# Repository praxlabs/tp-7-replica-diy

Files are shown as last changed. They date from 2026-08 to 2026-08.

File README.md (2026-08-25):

# DIY TP-7: Motorized-Reel Field Recorder (Open Source Hardware & Firmware)

An open-source digital replica and hardware implementation of the **Teenage Engineering TP-7 Field Recorder**. Features a physical motorized tape reel spool, contactless magnetic angle scrubbing, digital MEMS microphone recording, 24-bit I2S audio processing, dual-stage rocker shuttle, and Bluetooth LE transcription streaming on an **ESP32-WROOM-32E** dual-core microcontroller.

---

## 🌟 Quick Links & Documentation Index

| Resource | Description | Format |
| :--- | :--- | :--- |
| 🕹️ [**Digital Twin Simulator**](index.html) | Interactive web-based hardware simulator with Web Audio engine and touch scrubbing | `HTML5 / JS` |
| 📘 [**Documentation CLI Hub**](documentation.cmd) | Interactive Windows command center for all guides, sketches, and tools | `documentation.cmd` |
| 🔌 [**Breadboard Prototyping Guide**](Breadboard-Prototyping-Guide.md) | Step-by-step wiring diagrams, dual-rail layout, and noise isolation rules | `Markdown` |
| 🧪 [**Breadboard Hardware Diagnostic Tool**](TP7_Replica/Breadboard_Subsystem_Tester.ino) | Interactive serial monitor diagnostic tool for testing sensors and motors | `Arduino (.ino)` |
| 💻 [**Main Firmware (v2.0)**](TP7_Replica/TP7_Replica.ino) | FreeRTOS dual-core firmware with touch-to-pause and memo recording | `Arduino (.ino)` |
| 🛠️ [**Arduino & ESP32 Setup Guide**](Arduino-Prototyping-Setup-Guide.md) | Complete guide for configuring Arduino IDE 2.x and flashing the ESP32 | `Markdown` |
| 📐 [**Custom PCB & Manufacturing Guide**](PCB-Design-And-Manufacturing-Guide.md) | 4-layer PCB stackup, KiCad netlist, and Gerber ordering instructions | `Markdown` |
| 📋 [**Required Parts List & Sourcing BOM**](Required-Parts-List-And-Sourcing.md) | Full bill of materials with footprints, part numbers, and suppliers | `Markdown` |
| ⚖️ [**Commercialization & Legal Guide**](DIY-TP7-Commercialization-And-Legal-Guide.pdf) | IP analysis (trade dress, patents, trademarks), FCC/CE, and battery laws | `PDF Document` |
| 🧊 [**3D Printable STL Files**](3D_Models/) | Production-ready STL models for unibody chassis, motorized reel, and rocker | `3D STL Files` |

---

## 📐 System Architecture

```
                          ┌─────────────────────────────┐
                          │         ESP32-WROOM         │
                          │   (Dual-Core 240MHz, BLE)   │
                          └───────────────┬─────────────┘
         ┌───────────┬───────────┬────────┼────────┬───────────┬───────────┐
         │           │           │        │        │           │           │
    I2S Mic      I2S Amp     I2C Bus   SPI Bus   PWM/GPIO    UART/USB   ADC (Batt)
   (INMP441)   (MAX98357A)  (AS5600  (microSD)  (DRV8833     (USB-C     (Voltage
                             Encoder,            Motor,       Audio /    Divider)
                             SSD1306             Buttons)     Data)
                             OLED)
```

### FreeRTOS Dual-Core Task Allocation
* **Core 1 (High Real-Time Priority - Pri 3):** Dedicated 44.1kHz / 16-bit I2S DMA double-buffered audio streaming for INMP441 microphone recording and MAX98357A Class-D speaker playback.
* **Core 0 (UI & Motor Loop - 500 Hz):** Polls the AS5600 magnetic rotary sensor via fast I2C, computes angular velocity, detects user touch-to-pause motor stall, and drives DRV8833 H-bridge PWM.

---

## 🎛️ Key Hardware Features (Teenage Engineering TP-7 Specifications)

1. **Motorized Tape Reel (Signature Mechanism):**
   * Driven by an N20 micro metal gearmotor (100:1 reduction) via DRV8833 PWM.
   * Position tracked by an **AS5600 12-bit contactless magnetic encoder** (4096 counts per rotation) paired with a 6x3mm N35 diametric magnet.
   * **Touch-to-Pause:** Placing a finger on the spinning reel detects motor stall through angular velocity differentiation, smoothly halting playback without stopping the tape head.
2. **Dedicated Controls:**
   * **MEMO Button:** Instant hold-to-record voice memo shortcut.
   * **REC Button:** Project recording toggle with red LED status glow.
   * **PLAY / PAUSE:** Standard playback toggle.
   * **2-Stage Rocker Switch:** Fast-forward and rewind shuttle scrub with speed acceleration.
3. **Multi-Jack Audio I/O:**
   * 3x 3.5mm TRRS two-way jacks for stereo line-in, microphone input, cue monitoring, and headphones.
4. **Wireless Companion Sync:**
   * Streams audio chunks over Bluetooth Low Energy (BLE) for real-time speech transcription.

---

## 🚀 How to Run the Project

### 1. Launch the Digital Twin Simulator
Open [`index.html`](index.html) in Google Chrome, Firefox, or Edge. You can interact with the virtual motorized reel, record via your computer microphone, and test audio scrubbing directly in your browser.

### 2. Open the Documentation Hub
Double-click [`documentation.cmd`](documentation.cmd) on Windows to launch an interactive menu for accessing all guides, schematics, 3D STL files, and firmware sketches.

### 3. Flash to Hardware
1. Connect your ESP32 board via USB.
2. Open [`TP7_Replica/TP7_Replica.ino`](TP7_Replica/TP7_Replica.ino) in **Arduino IDE**.
3. Select **Board: ESP32 Dev Module** and click **Upload**.

---

## 📜 License & Compliance Note
This project is open-source hardware and software created for educational, prototyping, and research purposes. *"TP-7"*, *"Teenage Engineering"*, and *"Field System"* are registered trademarks of Teenage Engineering AB. Please review [`DIY-TP7-Commercialization-And-Legal-Guide.pdf`](DIY-TP7-Commercialization-And-Legal-Guide.pdf) before considering any commercial distribution.

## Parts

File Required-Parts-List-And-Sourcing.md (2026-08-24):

# DIY TP-7 Field Recorder: Required Parts List & Sourcing Guide

A complete, production-ready Bill of Materials (BOM) for building the DIY Teenage Engineering TP-7 Replica. Every component has been selected for optimal audio fidelity, low mechanical jitter, power efficiency, and compact fit inside the 3D-printed or CNC enclosure.

---

## 1. Primary Electronics & ICs

| Ref Des | Part Name | Manufacturer / MPN | Package / Footprint | Description | Est. Cost (USD) | Sourcing Options |
| :--- | :--- | :--- | :--- | :--- | :--- | :--- |
| **U1** | **ESP32-WROOM-32E** | Espressif Systems (`ESP32-WROOM-32E-N4` or DevKitC) | SMD Module (or 38-pin DIP DevBoard) | Dual-Core 240MHz MCU, 4MB Flash, BT/BLE 4.2, I2S Hardware Controller | $3.50 – $6.00 | [DigiKey](https://www.digikey.com) / [LCSC](https://www.lcsc.com) / [Mouser](https://www.mouser.com) |
| **U2** | **INMP441 MEMS Mic** | TDK InvenSense (`INMP441ACEZ-R7`) | Bottom-Port LGA-14 / Breakout | Omnidirectional Digital Microphone with integrated 24-bit I2S ADC (61 dB SNR) | $2.20 – $3.50 | [AliExpress](https://aliexpress.com) / [LCSC](https://www.lcsc.com) / [Amazon](https://amazon.com) |
| **U3** | **MAX98357A Amp** | Analog Devices / Maxim (`MAX98357AETE+T`) | 16-TQFN / Breakout | 3.2W Mono Class-D Audio Amplifier with built-in I2S DAC | $2.50 – $4.00 | [DigiKey](https://www.digikey.com) / [Adafruit](https://www.adafruit.com) / [LCSC](https://www.lcsc.com) |
| **U4** | **AS5600 Angle Sensor** | ams OSRAM (`AS5600-ASOT`) | SOIC-8 / Breakout Module | 12-Bit Programmable Contactless Magnetic Rotary Position Sensor (I2C 0x36) | $1.80 – $3.00 | [LCSC](https://www.lcsc.com) / [AliExpress](https://aliexpress.com) |
| **U5** | **DRV8833 Motor Driver** | Texas Instruments (`DRV8833PWPR`) | 16-HTSSOP / Breakout | Dual H-Bridge Motor Driver (1.5A RMS per channel, PWM speed control) | $1.50 – $2.50 | [DigiKey](https://www.digikey.com) / [LCSC](https://www.lcsc.com) / [Pololu](https://www.pololu.com) |
| **U6** | **WM8960 Audio Codec** | Cirrus Logic (`WM8960CGEFL/RV`) | 32-QFN / Waveshare Breakout | Low Power Stereo Codec with Class D Speaker Driver & 24-bit Stereo ADC/DAC | $7.00 – $11.00 | [LCSC](https://www.lcsc.com) / [Mouser](https://www.mouser.com) / [Waveshare](https://www.waveshare.com) |
| **U7** | **TP4056 + DW01A** | NanJing Top Power (`TP4056`) | SOP-8 / USB-C Charge Board | 1A Standalone Linear Li-Ion Battery Charger with Overcharge/Overdischarge Protection | $0.80 – $1.50 | [AliExpress](https://aliexpress.com) / [Amazon](https://amazon.com) |
| **DISP1** | **0.96" OLED Display** | Solomon Systech (`SSD1306` / `SSD1315`) | 128x64 I2C Monochrome OLED | Ultra-high contrast display for timecode, VU meters, file names, and battery level | $2.50 – $4.50 | [AliExpress](https://aliexpress.com) / [Amazon](https://amazon.com) |

---

## 2. Electromechanical, Motors & Mechanism

| Ref Des | Item Description | Specifications | Function / Notes | Est. Cost (USD) | Sourcing Options |
| :--- | :--- | :--- | :--- | :--- | :--- |
| **M1** | **N20 Micro Metal Gearmotor** | 6V 100RPM – 150RPM (100:1 reduction, 3mm D-Shaft) | Drives the tape reel spool smoothly without excessive gear chatter | $2.50 – $4.00 | [AliExpress](https://aliexpress.com) / [Pololu](https://www.pololu.com) / [Amazon](https://amazon.com) |
| **MAG1** | **Diametric Neodymium Magnet** | 6mm Diameter x 3mm Thickness, N35 / N52 | **Crucial:** Must be *diametrically magnetized* (poles on curved sides) for AS5600 | $0.80 – $1.50 | [SuperMagnetMan](https://supermagnetman.com) / [K&J Magnetics](https://kjmagnetics.com) / [AliExpress](https://aliexpress.com) |
| **SPK1** | **Miniature Dynamic Speaker** | 8 Ohm 1W – 2W, 20mm round x 4mm slim | Internal monitoring speaker | $1.20 – $2.00 | [DigiKey](https://www.digikey.com) / [LCSC](https://www.lcsc.com) |
| **J1, J2, J3** | **3.5mm TRRS Audio Jacks** | PJ-320A / CUI Devices `SJ-43514-SMT` | 4-Pole stereo + mic I/O jacks (Tip, Ring 1, Ring 2, Sleeve) | $0.60 ea ($1.80 total) | [LCSC](https://www.lcsc.com) / [DigiKey](https://www.digikey.com) |
| **J4** | **microSD Card Socket** | Push-Push SPI/SDIO SMD Socket | High-speed FAT32 / exFAT storage for 44.1kHz / 96kHz PCM WAV files | $0.70 – $1.20 | [LCSC](https://www.lcsc.com) / [DigiKey](https://www.digikey.com) |
| **J5** | **USB-C 16-Pin Receptacle** | TYPE-C 16P Female SMD (`TYPE-C-31-M-12`) | 5V 1A charging + USB Mass Storage / UAC 2.0 Audio Interface data | $0.40 – $0.90 | [LCSC](https://www.lcsc.com) |
| **SW1–SW4** | **Tactile SMD Pushbuttons** | 6x6x5mm or 4x4x1.5mm Soft-Click SMD | Record, Memo, Play/Stop, Mode switches | $0.15 ea ($0.60 total) | [LCSC](https://www.lcsc.com) / [DigiKey](https://www.digikey.com) |
| **SW5** | **2-Way Rocker Switch** | SPDT Center-Off Momentary Seesaw Rocker | Side Fast-Forward / Rewind shuttle control | $1.50 – $2.50 | [AliExpress](https://aliexpress.com) / [Mouser](https://www.mouser.com) |
| **BATT1** | **Rechargeable LiPo Cell** | 3.7V 1S 500mAh – 1000mAh (Model 602535 / 803040) | Provides 4 to 8 hours of continuous field recording | $4.50 – $7.00 | [Adafruit](https://www.adafruit.com) / [Amazon](https://amazon.com) |

---

## 3. Passive Components & Hardware Fasteners

| Quantity | Component Type | Value / Rating | Purpose |
| :--- | :--- | :--- | :--- |
| **8** | Ceramic Capacitor 0805 | 100nF (0.1µF) 50V X7R | High-frequency power rail decoupling |
| **4** | Tantalum / Electrolytic Cap | 10µF – 100µF 10V | Bulk decoupling for motor drive and audio amp |
| **4** | SMD Resistor 0805 | 4.7 kΩ 1% | I2C pull-up resistors for SDA / SCL lines |
| **2** | SMD Resistor 0805 | 5.1 kΩ 1% | USB Type-C CC1 / CC2 pull-down resistors (standard 5V negotiation) |
| **2** | SMD Resistor 0805 | 330 Ω 1% | LED current limiting resistors |
| **2** | SMD LED 0805 | Red (REC active), Amber (Charging) | Hardware status indicators |
| **4** | M2 Socket Cap Screws | M2 x 6mm Stainless Steel | Chassis assembly & bottom lid fastening |
| **4** | M2 Brass Heat-Set Threaded Inserts | M2 x 3.5mm OD 3.2mm | Heat-pressed into 3D-printed chassis standoffs |
| **1** | Miniature Ball Bearing (Optional) | 683ZZ (3mm ID x 7mm OD x 3mm Width) | Eliminates reel wobble and ensures whisper-quiet motorized spinning |

---

## 4. 3D Printable Enclosure Parts (Included in `/3D_Models`)

| File Name | Recommended Filament | Infill & Layer Height | Print Notes |
| :--- | :--- | :--- | :--- |
| `TP7_Main_Chassis_Top.stl` | Matte Black PETG or PLA Pro | 25% Gyroid, 0.16mm layer height | Print top-face up with tree supports for jack recesses |
| `TP7_Chassis_Bottom_Lid.stl` | Matte Black PETG / PLA Pro | 30% Infill, 0.20mm layer height | Flat on print bed, no supports needed |
| `TP7_Motorized_Tape_Reel.stl` | Silver / Anodized Grey PETG or Resin | 100% Solid, 0.12mm (Resin preferred) | Ensures smooth balanced rotation around N20 shaft |
| `TP7_Side_Rocker_Switch.stl` | Orange or Black PETG | 100% Solid, 0.12mm | High wear resistance for finger shuttle action |
| `TP7_Tactile_Button_Caps.stl` | Orange (REC) & Black (Play/Mode) | 100% Solid, 0.12mm | Print in sets of 4 |

---

## 5. Total Project Cost Summary

* **DIY Hand-Wired Prototype (Using Breakout Modules):** ~$45.00 – $65.00
* **Custom SMT Assembled PCB (JLCPCB 5-Board Run):** ~$75.00 – $95.00 total
* **Comparison with OEM Teenage Engineering TP-7:** **$1,499.00 retail** (Save over 94% while building your own customized field recorder!)

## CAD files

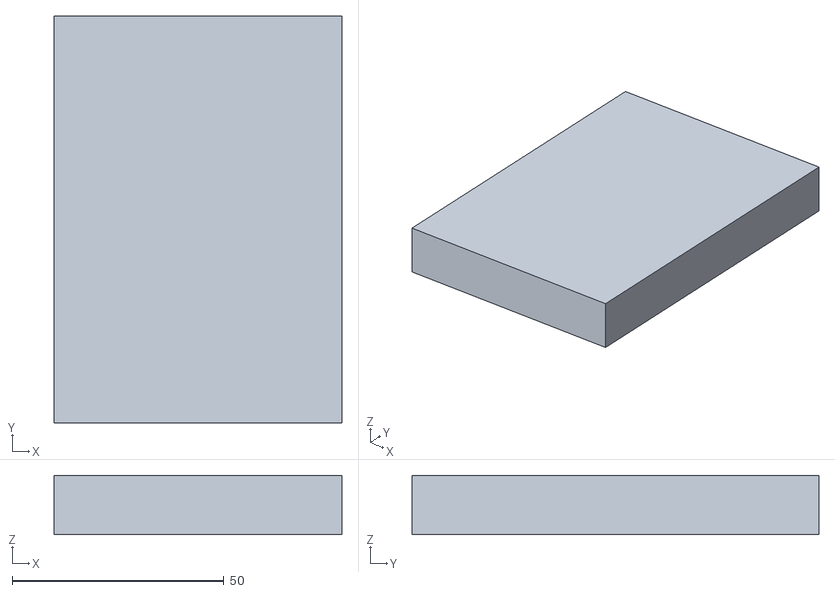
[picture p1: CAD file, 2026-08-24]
3D_Models/TP7_Main_Chassis_Top.stl
68.0 x 96.0 x 14.0

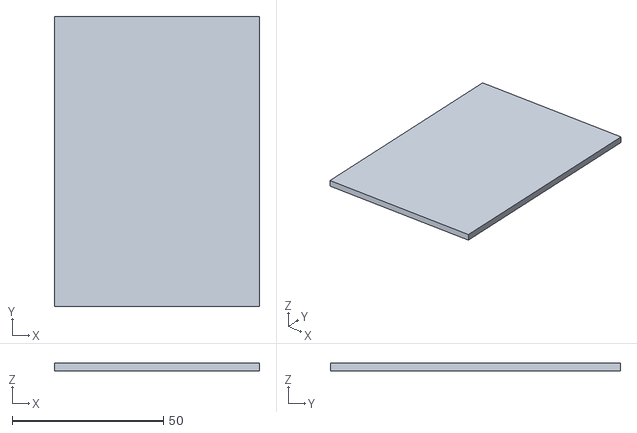
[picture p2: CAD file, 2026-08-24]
3D_Models/TP7_Chassis_Bottom_Lid.stl
68.0 x 96.0 x 2.50

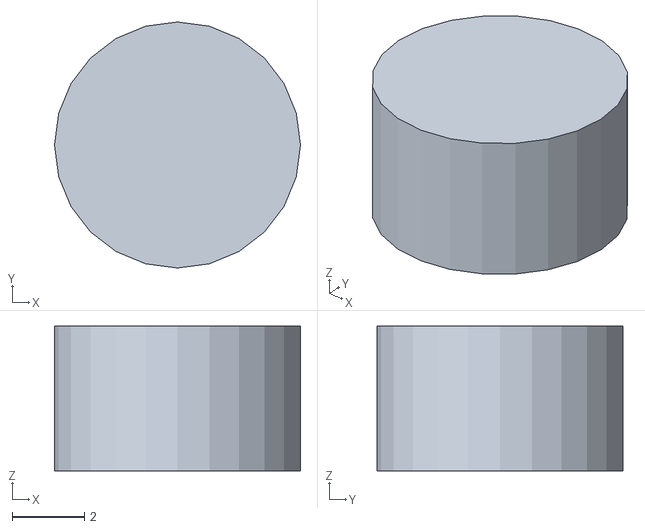
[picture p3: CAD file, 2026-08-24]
3D_Models/TP7_Tactile_Button_Caps.stl
6.80 x 6.80 x 4.00

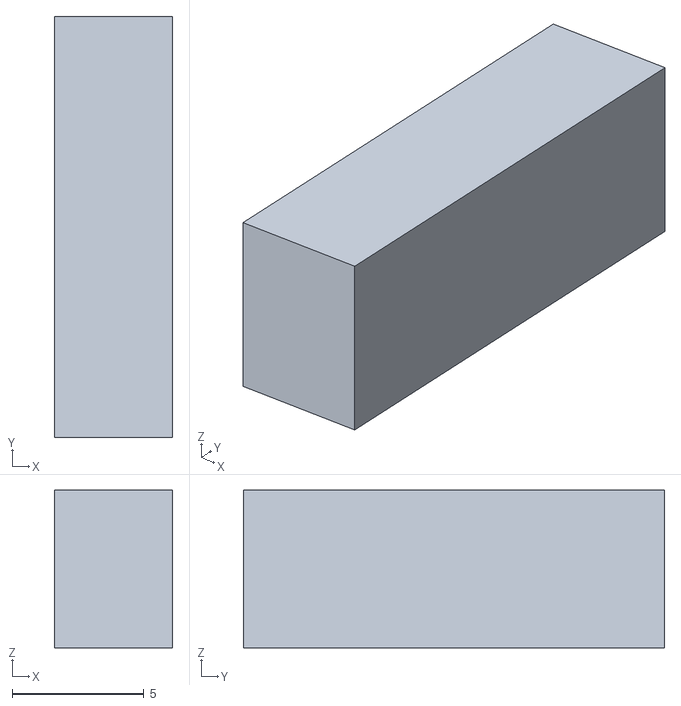
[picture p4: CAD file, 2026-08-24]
3D_Models/TP7_Side_Rocker_Switch.stl
4.50 x 16.0 x 6.00

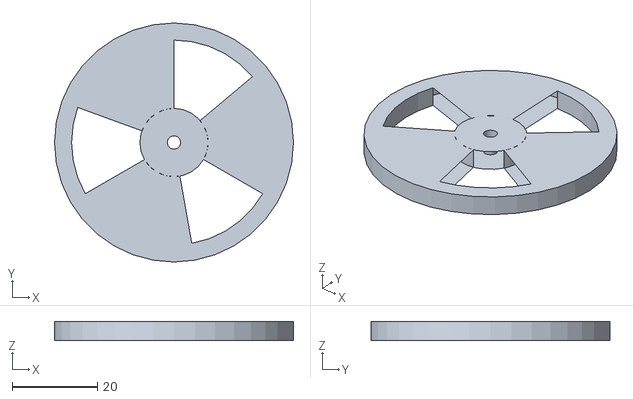
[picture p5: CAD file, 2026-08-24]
3D_Models/TP7_Motorized_Tape_Reel.stl
56.0 x 56.0 x 4.50

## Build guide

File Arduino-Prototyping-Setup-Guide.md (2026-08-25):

# Arduino IDE & ESP32 Prototyping Setup Guide

This guide shows you how to set up **Arduino IDE** to compile, test, and flash your breadboard prototype of the DIY TP-7 Field Recorder.

---

## 1. Installed Prototyping Software Suite

The following development environment has been installed on your system:
* **Arduino IDE 2.x:** Complete C++ development environment and Serial Monitor for ESP32.
* **KiCad 10.0.5:** Schematic capture, breadboard netlist viewer, and PCB layout designer.
* **Python 3.12 & esptool:** For direct high-speed serial flashing and bootloader diagnostics.

---

## 2. Setting Up ESP32 Board Support in Arduino IDE

1. Open **Arduino IDE**.
2. Open **File > Preferences** (or press `Ctrl + ,`).
3. In the **Additional boards manager URLs** field, paste the official Espressif ESP32 package URL:
   ```
   https://raw.githubusercontent.com/espressif/arduino-esp32/gh-pages/package_esp32_index.json
   ```
4. Click **OK**.
5. Go to **Tools > Board > Boards Manager...** (or click the Board icon on the left sidebar).
6. Search for `esp32` and click **Install** on **esp32 by Espressif Systems**.

---

## 3. Recommended Arduino IDE Settings for DIY TP-7

When plugging your ESP32 DevKitC into USB, configure the **Tools** menu as follows:

| Setting | Value | Why |
| :--- | :--- | :--- |
| **Board** | `ESP32 Dev Module` | Standard pin mapping for 30-pin & 38-pin DevKit boards |
| **Upload Speed** | `921600` (or `115200`) | High-speed flashing |
| **CPU Frequency** | `240MHz (WiFi/BT)` | Maximum dual-core performance for real-time I2S DMA |
| **Flash Frequency** | `80MHz` | Fast code execution from SPI Flash |
| **Flash Mode** | `QIO` | Quad SPI mode |
| **Partition Scheme** | `Huge APP (3MB No OTA/1MB SPIFFS)` | Gives full memory space for BLE and audio buffer tasks |
| **Port** | `COM3` / `COM4` (your USB-to-UART port) | Select your connected ESP32 serial port |

---

## 4. Required Arduino Libraries

The TP-7 firmware uses native ESP32 FreeRTOS drivers (`driver/i2s.h`, `SPI.h`, `SD.h`, `Wire.h`, `BLEDevice.h`), so **no external 3rd-party library downloads are required**! Everything compiles out of the box with the core ESP32 board package.

*(Optional: For OLED display graphical animations, you can install `Adafruit SSD1306` and `Adafruit GFX` from **Tools > Manage Libraries**).*

---

## 5. Breadboard First-Flash Walkthrough

1. Connect your breadboarded ESP32 to your PC via a micro-USB or USB-C data cable.
2. In Arduino IDE, open [`TP7_Replica/Breadboard_Subsystem_Tester.ino`](file:///c:/Users/PRAKHYAT%20SURAPANENI/OneDrive/Desktop/tp%207%20replica%20a/TP7_Replica/Breadboard_Subsystem_Tester.ino).
3. Click the **Upload** arrow button (or press `Ctrl + U`).
4. Once flashed, open **Tools > Serial Monitor** (`Ctrl + Shift + M`) and set baud rate to **115200**.
5. Press `1` to scan the I2C bus, `2` to track reel angle, or `5` to hear a test tone through your speaker!
6. Once all breadboard modules pass diagnostics, open [`TP7_Replica/TP7_Replica.ino`](file:///c:/Users/PRAKHYAT%20SURAPANENI/OneDrive/Desktop/tp%207%20replica%20a/TP7_Replica/TP7_Replica.ino) and upload the full field recorder firmware.

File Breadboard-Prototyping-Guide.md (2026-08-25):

# DIY TP-7: Complete Breadboard Prototyping Guide

This guide is a step-by-step blueprint for building a fully working **DIY TP-7 Motorized-Reel Field Recorder** on solderless breadboards before committing to a custom PCB or permanent enclosure.

---

## 1. Breadboard Tools & Materials Needed

| Item | Recommendation | Purpose |
| :--- | :--- | :--- |
| **Solderless Breadboard** | 2x Standard 830 Tie-Point Breadboards (interlocked side-by-side) | Dual breadboards provide ample space for the wide ESP32 DevKitC board + 6 breakout modules without cramped wiring. |
| **Jumper Wires** | 65-piece Male-to-Male flexible wire bundle + 20-piece Male-to-Female ribbons | Short, flat jumper wires keep signal capacitance low for I2S audio and SPI clock. |
| **Decoupling Capacitors** | 4x 100nF (0.1µF) Ceramic + 2x 100µF Electrolytic | Critical for breadboards to suppress contact bounce and motor PWM voltage dips. |
| **Multimeter** | Any standard digital multimeter | Verifying 3.3V / 5.0V voltage rails and checking continuity before power-up. |
| **Power Source** | USB-C cable plugged into ESP32 DevKitC (or 5V breadboard power supply module) | Provides clean 5V and on-board regulated 3.3V rail. |

---

## 2. Breadboard Layout & Power Distribution Architecture

Because the TP-7 combines **high-speed digital audio (I2S DMA)**, **high-current motor switching (DRV8833)**, and **sensitive magnetic sensing (AS5600)**, proper breadboard component placement is essential to eliminate audio buzz:

```
========================================================================================
                                BREADBOARD 1 (AUDIO & MCU)
========================================================================================
   [+ 5V Rail -------------------------------------------------------------------------]
   [- GND Rail ------------------------------------------------------------------------]

     +-----------------------+     +-------------------+     +--------------------+
     |   INMP441 MEMS MIC    |     |  ESP32 DEVKITC    |     |  MAX98357A I2S AMP |
     | (I2S RX Master Bus 0) |     |  (38-Pin Module)  |     | (I2S TX Master 1)  |
     +-----------------------+     +-------------------+     +--------------------+
                │                            │                          │
                ▼                            ▼                          ▼
          Left Channel                  Dual-Core MCU              8Ω 1W Speaker
          (Tie L/R to GND)              (Audio + UI)               (Mono Output)

   [- GND Rail ------------------------------------------------------------------------]
   [+ 3.3V Rail -----------------------------------------------------------------------]
========================================================================================
                                BREADBOARD 2 (STORAGE & MECHANISM)
========================================================================================
   [+ 5V / Batt Rail ------------------------------------------------------------------]
   [- GND Rail (COMMON GROUND TIE) ----------------------------------------------------]

     +-----------------------+     +-------------------+     +--------------------+
     |   SPI MicroSD MODULE  |     |  AS5600 ENCODER   |     |  DRV8833 H-BRIDGE  |
     | (FAT32 WAV Streamer)  |     |  (12-Bit I2C Reel)|     |  (N20 Motor Drive) |
     +-----------------------+     +-------------------+     +--------------------+
                │                            │                          │
                ▼                            ▼                          ▼
          SPI Bus Pins                  Directly under              N20 Gearmotor
          (13, 12, 23, 5)               Magnet Shaft                (100:1, 3mm D)

   [- GND Rail ------------------------------------------------------------------------]
   [+ 3.3V Rail -----------------------------------------------------------------------]
```

---

## 3. Step-by-Step Subsystem Wiring Matrix

### Subsystem 1: Power & Common Ground
* Connect the **GND pin** of the ESP32 to the blue breadboard ground rails.
* Connect the **3V3 pin** of the ESP32 to the red 3.3V power rails.
* Connect the **VIN / 5V pin** of the ESP32 to the 5V power rail (used to power the MAX98357A audio amp for maximum speaker loudness).
* **Crucial:** Interconnect all breadboard ground rails so the entire circuit shares a single, low-impedance ground reference.

---

### Subsystem 2: INMP441 Digital MEMS Microphone (I2S Bus 0)
The INMP441 provides studio-quality digital audio with zero analog noise pickup.

| INMP441 Pin | ESP32 GPIO Pin | Wire Color Recommendation | Function |
| :--- | :--- | :--- | :--- |
| **VDD** | 3.3V Power Rail | Red | 3.3V DC Power |
| **GND** | GND Ground Rail | Black | Power & Signal Ground |
| **SD** | **GPIO 33** | Blue | Serial PCM Audio Data |
| **WS** | **GPIO 25** | Yellow | Word Select (Left/Right clock, 44.1 kHz) |
| **SCK** | **GPIO 26** | Green | Bit Clock (Continuous I2S Clock, 2.822 MHz) |
| **L/R** | **GND** | Black | Selects Left audio channel |

---

### Subsystem 3: MAX98357A I2S Class-D Amplifier & Speaker (I2S Bus 1)
Using a second dedicated I2S port prevents input/output bus contention.

| MAX98357A Pin | ESP32 / Connection | Wire Color Recommendation | Function |
| :--- | :--- | :--- | :--- |
| **VIN** | **5V Power Rail** (or 3.3V) | Red | Class-D Power Supply |
| **GND** | GND Ground Rail | Black | Ground |
| **DIN** | **GPIO 22** | Blue | Audio Sample Data In |
| **BCLK** | **GPIO 27** | Green | Bit Clock |
| **LRC** | **GPIO 14** | Yellow | Left/Right Word Select Clock |
| **SD / GAIN** | Leave Unconnected (or 3.3V) | — | 12dB default gain, auto-stereo mix |
| **+ / − (Screw Terminals)** | **8Ω 1W Speaker Terminals** | Red / Black Pair | Direct acoustic output |

---

### Subsystem 4: MicroSD Card Storage Module (SPI Bus)
Streams raw 16-bit 44.1kHz PCM samples directly to standard `.wav` files.

| MicroSD Module Pin | ESP32 GPIO Pin | Wire Color Recommendation | Function |
| :--- | :--- | :--- | :--- |
| **VCC** | 3.3V Power Rail (or 5V if module has 3.3V regulator) | Red | Power |
| **GND** | GND Ground Rail | Black | Ground |
| **CS** | **GPIO 5** | Orange | SPI Chip Select |
| **MOSI** | **GPIO 23** | Blue | SPI Master Out Slave In |
| **MISO** | **GPIO 12** | Green | SPI Master In Slave Out |
| **SCK** | **GPIO 13** | Yellow | SPI Clock (20 MHz) |

---

### Subsystem 5: AS5600 Magnetic Angle Sensor (I2C Bus)
The AS5600 contactless sensor measures the tape reel rotation angle with 12-bit precision (4096 steps per turn).

| AS5600 Module Pin | ESP32 GPIO Pin | Wire Color Recommendation | Function |
| :--- | :--- | :--- | :--- |
| **VCC** | 3.3V Power Rail | Red | 3.3V Power |
| **GND** | GND Ground Rail | Black | Ground |
| **SDA** | **GPIO 21** | Blue | I2C Serial Data (with 4.7kΩ pull-up) |
| **SCL** | **GPIO 15** | Yellow | I2C Serial Clock (with 4.7kΩ pull-up) |
| **DIR** | GND (Clockwise positive) | Black | Direction selection |

---

### Subsystem 6: DRV8833 Dual H-Bridge & N20 Motor Rig
Drives the tape spool forward during recording/playback and reverse during rewind.

| DRV8833 Pin | ESP32 / Connection | Wire Color Recommendation | Function |
| :--- | :--- | :--- | :--- |
| **VM** | **5V Power Rail** (or LiPo Battery +) | Red | Motor Supply Voltage |
| **GND** | GND Ground Rail | Black | Ground |
| **IN1** | **GPIO 18** | Orange | Motor Forward PWM (LEDC Ch 0) |
| **IN2** | **GPIO 19** | Yellow | Motor Reverse PWM (LEDC Ch 1) |
| **OUT1 / OUT2** | **N20 Motor 2 Terminals** | Red / Black Pair | DC Gearmotor Power |
| **EEP (Sleep)** | **3.3V Power Rail** | Red | Active-high enable |

---

### Subsystem 7: Tactile Buttons & Rocker Switch

| Component | ESP32 GPIO Pin | Wiring Mode | Action Triggered |
| :--- | :--- | :--- | :--- |
| **REC Button** | **GPIO 32** | Pin to Ground (`INPUT_PULLUP`) | Toggles project recording |
| **MEMO Button** | **GPIO 34** | Pin to Ground (`INPUT_PULLUP`) | Instant hold-to-record voice note |
| **PLAY / STOP** | **GPIO 35** | Pin to Ground (`INPUT_PULLUP`) | Starts / pauses playback |
| **MODE Button** | **GPIO 36** | Pin to Ground (`INPUT_PULLUP`) | Cycles field recording modes |
| **Rocker FWD** | **GPIO 39** | Pin to Ground (`INPUT_PULLUP`) | Fast-forward shuttle scrub |
| **Rocker REW** | **GPIO 4** | Pin to Ground (`INPUT_PULLUP`) | Rewind shuttle scrub |
| **REC LED** | **GPIO 2** | In series with 330Ω resistor to GND | Red recording glow ring |

---

## 4. Breadboard Noise Reduction & Prototyping Rules

Solderless breadboards introduce stray capacitance and ground resistance. Follow these 4 golden rules to guarantee clean audio:

1. **Keep I2S & SPI Wires Short (<10 cm / 4 in)**: Long jumper wires act as antennas. Keep clock lines (`SCK`, `BCLK`, `WS`) as direct and short as possible.
2. **Add a 100µF Bulk Capacitor Near the Motor Driver**: Place an electrolytic capacitor right across the DRV8833 `VM` and `GND` pins on the breadboard. This absorbs inductive current spikes when the motor starts or stops.
3. **Decouple 3.3V Rail**: Place a 100nF (0.1µF) ceramic capacitor across 3.3V and GND right next to the INMP441 microphone and AS5600 sensor.
4. **Mechanical Jig for the AS5600 Magnet**:
   * Mount the N35 6x3mm diametric magnet onto the N20 motor shaft.
   * Position the AS5600 breakout board so the IC chip is suspended **0.8 mm to 1.5 mm directly beneath the magnet**.

---

## 5. Breadboard Testing & Verification Sequence

Before flashing the full FreeRTOS firmware, verify each subsystem sequentially using the included [`TP7_Replica/Breadboard_Subsystem_Tester.ino`](file:///c:/Users/PRAKHYAT%20SURAPANENI/OneDrive/Desktop/tp%207%20replica%20a/TP7_Replica/Breadboard_Subsystem_Tester.ino) sketch:

1. **Step 1: Smoke & Voltage Test**
   * Plug in USB-C.
   * Measure 3.3V rail with multimeter: Must read between **3.25V and 3.35V**.
   * Verify ESP32 power LED turns on and no components get hot to the touch.

2. **Step 2: I2C Scanner Test (AS5600)**
   * Open Serial Monitor at **115200 baud**.
   * Run I2C scan: Sensor should respond at address `0x36`.
   * Spin the magnet by hand: Angle in serial monitor should smoothly track from `0°` to `359°` (`0` to `4095` counts).

3. **Step 3: MicroSD SPI Mount Test**
   * Insert FAT32 formatted microSD card (16GB–128GB).
   * Verify serial reports: `[OK] MicroSD Card Mounted. Total Space: 124.8 GB`.

4. **Step 4: I2S Audio Loopback Test**
   * Speak into the INMP441 microphone for 3 seconds.
   * Audio is recorded directly to `TEST_REC.WAV` on the microSD card and immediately played back through the MAX98357A speaker!

5. **Step 5: Motor PWM & Touch-to-Pause Test**
   * Motor spins forward at 80/255 duty cycle.
   * Grab the motor shaft with your fingers: Verify Serial reports `[TOUCH-PAUSE DETECTED: Motor Stalled]`.
   * Release shaft: Verify motor smoothly resumes spinning!

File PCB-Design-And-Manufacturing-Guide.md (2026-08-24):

# Custom PCB Design & Manufacturing Guide for DIY TP-7

This guide walks you through designing, ordering, and assembling the custom mainboard PCB for the **DIY TP-7 Motorized-Reel Field Recorder**.

---

## 1. PCB Software Installation & Setup

We recommend **KiCad (v8/v10)**, the industry-standard open-source electronics design automation (EDA) suite.

### Installing KiCad on Windows
1. Open PowerShell or Command Prompt.
2. Run the automated winget installer:
   ```powershell
   winget install --id KiCad.KiCad -e --accept-package-agreements --accept-source-agreements
   ```
3. Alternatively, download the direct installer from [kicad.org/download](https://www.kicad.org/download/windows/).

---

## 2. Board Dimensions & Mechanical Constraints

| Parameter | Value | Reason |
| :--- | :--- | :--- |
| **Dimensions** | 64.0 mm x 92.0 mm (with 3.0mm corner radiuses) | Fits snugly within the 68mm x 96mm aluminum/3D chassis |
| **Board Thickness** | 1.6 mm (FR-4) | Standard thickness, rigid under motor torque |
| **Layer Count** | 4 Layers (Signal / GND / Power / Signal) | Superior ground return paths for whisper-quiet audio SNR |
| **Copper Weight** | 1 oz (35 µm) outer, 1 oz inner | Adequate current capacity for N20 motor pulses (up to 500mA) |
| **Solder Mask** | Matte Black or Aluminum White | Matches Teenage Engineering minimalist design language |
| **Surface Finish** | **ENIG (Electroless Nickel Immersion Gold)** | Flat pads for LGA MEMS mic & reliable button contacts |

```
                       64.0 mm
         ┌───────────────────────────────────┐
         │ [3.5mm-1]  [3.5mm-2]  [3.5mm-3]   │ ◄ Top Audio Jacks
         │                                   │
         │   ┌────────┐        ┌─────────┐   │
         │   │ OLED   │        │ MEMS    │   │ ◄ SSD1306 Display & INMP441 Mic
         │   └────────┘        └─────────┘   │
  92.0   │                                   │
  mm     │             ┌──────┐              │
         │   [Rocker]  │AS5600│              │ ◄ AS5600 Magnet Sensor in Center
         │             └──────┘              │   (Aligned directly under reel shaft)
         │                                   │
         │   [REC]   [PLAY]   [STOP]  [MODE] │ ◄ Tactile Control Buttons
         │                                   │
         │            [ USB-C ]              │ ◄ Bottom USB-C Port
         └───────────────────────────────────┘
```

---

## 3. Schematic Pin Mapping & Electrical Interconnects

### ESP32-WROOM-32 Pin Allocation Table

```
+--------------------+--------------+-----------------------------------------------+
| ESP32 Pin Name     | GPIO Number  | Connected Peripheral & Protocol               |
+--------------------+--------------+-----------------------------------------------+
| GPIO25             | GPIO25       | INMP441 I2S_0 Word Select (WS / LRCLK)        |
| GPIO26             | GPIO26       | INMP441 I2S_0 Continuous Bit Clock (SCK/BCLK) |
| GPIO33             | GPIO33       | INMP441 I2S_0 Serial Data Input (SD)          |
| GPIO22             | GPIO22       | MAX98357A I2S_1 Data In (DIN)                 |
| GPIO27             | GPIO27       | MAX98357A I2S_1 Bit Clock (BCLK)              |
| GPIO14             | GPIO14       | MAX98357A I2S_1 Word Select (LRC / WS)        |
| GPIO21             | GPIO21       | I2C SDA (AS5600 0x36 & OLED 0x3C & WM8960)    |
| GPIO15 (or 22)     | GPIO15       | I2C SCL (Clock line with 4.7kΩ pullups)       |
| GPIO18             | GPIO18       | DRV8833 Motor H-Bridge Channel A (PWM Forward)|
| GPIO19             | GPIO19       | DRV8833 Motor H-Bridge Channel B (PWM Reverse)|
| GPIO5              | GPIO5        | microSD SPI Chip Select (CS)                  |
| GPIO23             | GPIO23       | microSD SPI Master Out Slave In (MOSI)        |
| GPIO19 (remap)     | GPIO12       | microSD SPI Master In Slave Out (MISO)        |
| GPIO18 (remap)     | GPIO13       | microSD SPI Serial Clock (SCK)                |
| GPIO32             | GPIO32       | REC Pushbutton (Active LOW, internal pull-up) |
| GPIO34             | GPIO34       | MEMO Pushbutton (Dedicated voice memo)        |
| GPIO35             | GPIO35       | PLAY/STOP Pushbutton                          |
| GPIO36 (VP)        | GPIO36       | MODE Pushbutton                               |
| GPIO39 (VN)        | GPIO39       | 2-Stage Rocker FF (Fast-Forward switch)       |
| GPIO4              | GPIO4        | 2-Stage Rocker REW (Rewind switch)            |
| GPIO2              | GPIO2        | Status LED (Red Record Ring Indicator)        |
| GPIO36 (ADC1_0)    | GPIO36       | Battery Voltage Divider (100kΩ / 100kΩ)       |
+--------------------+--------------+-----------------------------------------------+
```

---

## 4. Critical PCB Routing & Audio Isolation Rules

To prevent motor switching noise and digital I2S harmonics from bleeding into your audio recordings:

1. **Star Grounding & Solid Ground Plane**:
   - Layer 2 is a dedicated, uninterrupted **Ground Plane (GND)**.
   - Keep digital high-speed signals (SPI SCK at 20MHz, I2S BCLK at 2.8MHz) away from analog input traces.
2. **Motor Isolation & Decoupling**:
   - Place a **100µF low-ESR tantalum capacitor** right at the DRV8833 `VM` motor power pin.
   - Place **100nF ceramic capacitors** across the N20 motor terminals inside the casing to suppress inductive brush sparks.
3. **AS5600 Magnetic Placement**:
   - The AS5600 IC must be positioned **precisely at the geometric center** of the tape reel recess.
   - Keep the air gap between the rotating N35 diametric magnet and the top surface of the AS5600 IC between **0.5 mm and 1.5 mm**.
4. **USB-C CC Pull-Down Resistors**:
   - Populate **5.1 kΩ (±1%) resistors** from `CC1` to GND and `CC2` to GND. This ensures USB-C Power Delivery chargers reliably supply 5V 1A.

---

## 5. Exporting Gerbers & Ordering from JLCPCB / PCBWay

Once your layout is complete in KiCad:

1. **Run DRC (Design Rules Check)**: Ensure 0 clearance errors, minimum trace width 0.15mm (6 mil), minimum via hole 0.3mm.
2. **Plot Gerber Files**:
   - Go to `File` > `Plot` in KiCad PCB Editor.
   - Select layers: `F.Cu`, `B.Cu`, `In1.Cu`, `In2.Cu`, `F.Paste`, `B.Paste`, `F.Silkscreen`, `B.Silkscreen`, `F.Mask`, `B.Mask`, `Edge.Cuts`.
   - Click **Generate Drill Files** (`.drl` / Excellon format).
   - Zip all output files into `TP7_Gerber_v1.0.zip`.
3. **Upload to JLCPCB or PCBWay**:
   - Upload the ZIP file.
   - Set **Layers: 4**, **Surface Finish: ENIG**, **PCB Color: Matte Black**.
   - Optional: Enable **SMT Assembly** and upload the BOM (`Required-Parts-List-And-Sourcing.md`) and CPL centroid coordinates file.

---

## 6. SMT Assembly & Testing Checklist

- [ ] **Power Rail Check**: Measure resistance between 3.3V and GND (should be >10kΩ).
- [ ] **USB-C 5V Verification**: Plug in USB-C cable and verify TP4056 outputs 4.2V charging voltage to battery terminals.
- [ ] **Flash Firmware**: Connect USB-to-UART or ESP-Prog to test firmware upload.
- [ ] **I2C Bus Scan**: Verify AS5600 (`0x36`) and SSD1306 OLED (`0x3C`) respond on I2C bus.
- [ ] **Motor Rotation Test**: Test PWM spinning forward (CW) and reverse (CCW).
- [ ] **Audio Loopback**: Record a 5-second test clip through INMP441 mic to microSD, and verify clean playback through MAX98357A speaker.

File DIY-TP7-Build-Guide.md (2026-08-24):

# DIY TP-7: Building Your Own Motorized-Reel Field Recorder

A full technical deep-dive into cloning the core functionality of the Teenage Engineering TP-7: a pocket audio recorder with a motorized "tape reel," multi-jack I/O, USB-C audio interface, Bluetooth transcription hand-off, and single-hand tactile control.

This guide goes subsystem by subsystem: the physics of how each part works, the exact electrical interface, and the firmware that drives it.

---

## 1. System Architecture

```
                         ┌─────────────────────────────┐
                         │         ESP32-WROOM          │
                         │   (dual-core, 240MHz, BT+BLE)│
                         └───────────────┬───────────────┘
        ┌───────────┬───────────┬────────┼────────┬───────────┬───────────┐
        │           │           │        │        │           │           │
   I2S Mic      I2S Amp     I2C Bus   SPI Bus   PWM/GPIO    UART/USB   ADC (batt)
  (INMP441)   (MAX98357A)  (AS5600  (microSD)  (DRV8833     (USB-C     (voltage
                            encoder,            motor,       audio /    divider)
                            WM8960              buttons)     data)
                            codec)
```

Everything hangs off one MCU. The two hard real-time constraints are:
1. **Audio I/O** — must keep a steady sample clock or you get clicks/dropouts.
2. **Motor/encoder loop** — must poll fast enough (>500 Hz) for the reel to feel responsive under a fingertip.

Both are handled with FreeRTOS tasks pinned to separate cores on the ESP32 (audio on core 1, UI/motor on core 0), so a slow SD card write never stalls reel feedback.

---

## 2. Full Bill of Materials

| # | Part | Example / Part Number | Role | Approx. Cost |
|---|---|---|---|---|
| 1 | MCU dev board | ESP32-WROOM-32 DevKitC | Brain, BT, I2S, WiFi (OTA updates) | $6–10 |
| 2 | Digital MEMS mic | INMP441 (I2S) | Internal microphone | $3 |
| 3 | I2S Class-D amp | MAX98357A | Drives internal speaker | $4 |
| 4 | Speaker | 8Ω 1W 20mm round | Playback | $2 |
| 5 | Audio codec | WM8960 breakout | External TRRS in/out, line level | $8–12 |
| 6 | TRRS jacks x3 | PJ-320A 3.5mm 4-pole | External mic/headphone I/O | $1.50 ea |
| 7 | microSD breakout | SPI microSD module | Storage (use a 128GB+ card) | $2 |
| 8 | Magnetic rotary encoder | AS5600 (I2C, 12-bit) | Senses reel angle for scrubbing | $3 |
| 9 | Geared DC motor | 6mm N20 micro gearmotor | Spins the reel | $3 |
| 10 | Motor driver | DRV8833 breakout | Drives the N20 motor (H-bridge) | $2 |
| 11 | Diametric magnet | 6x3mm N35 | Mounted on reel shaft, read by AS5600 | $1 |
| 12 | USB-C breakout | USB-C PD/data breakout | Charging + data | $1.50 |
| 13 | LiPo charge/protect IC | TP4056 w/ protection | Battery charging + safety | $1.50 |
| 14 | Battery | 1S LiPo 500mAh | Power | $6 |
| 15 | Buttons | 6mm tactile x4 | Record, mode, play/stop | $0.20 ea |
| 16 | Rocker switch | SPDT momentary rocker (2 stages) | Scrub FF/RW | $2 |
| 17 | Status LED | RGB or single red | Record indicator | $0.20 |
| 18 | Perfboard / custom PCB | — | Assembly | $5–20 |
| 19 | 3D-printed enclosure | PETG/PLA | Housing + reel | filament |

**Total: roughly $60–90** in parts for a hand-built version, versus $1,499 retail — you're trading the CNC-milled aluminum body, brushless motor, and polished firmware for a DIY equivalent that hits the same functional points.

---

## 3. Microphone — Physical & Code

### Physically
The INMP441 is a **MEMS (Micro-Electro-Mechanical System) microphone**. Inside its package is a few-micron-thick silicon diaphragm suspended over a backplate, forming a capacitor. Sound pressure waves deflect the diaphragm, changing the capacitance. An on-chip ASIC senses that capacitance change, amplifies it, and — critically — runs it straight through a **sigma-delta ADC** on the same die. The chip outputs the result as a digital bitstream rather than an analog voltage, which means no external ADC or amplifier is needed and there's very little noise pickup on the wire to the MCU.

The digital protocol used is **I2S (Inter-IC Sound)**, a 3-wire synchronous serial bus:
- **BCLK (bit clock)** — toggles once per data bit
- **WS/LRCLK (word select)** — toggles once per audio sample, tells the receiver whether the current bits are the Left or Right channel
- **SD (serial data)** — the actual PCM sample bits, MSB first

The INMP441 is mono, and you select Left or Right channel by tying its `L/R` pin to GND (Left) or VDD (Right).

### Wiring
| INMP441 pin | ESP32 pin |
|---|---|
| VDD | 3.3V |
| GND | GND |
| WS | GPIO25 |
| SCK (bit clock) | GPIO26 |
| SD | GPIO33 |
| L/R | GND (selects left channel) |

### Code
```cpp
#include <driver/i2s.h>

#define I2S_WS   25
#define I2S_SCK  26
#define I2S_SD   33
#define I2S_PORT I2S_NUM_0
#define SAMPLE_RATE 44100

void micInit() {
  i2s_config_t cfg = {
    .mode = (i2s_mode_t)(I2S_MODE_MASTER | I2S_MODE_RX),
    .sample_rate = SAMPLE_RATE,
    .bits_per_sample = I2S_BITS_PER_SAMPLE_32BIT, // INMP441 outputs 24-bit in a 32-bit frame
    .channel_format = I2S_CHANNEL_FMT_ONLY_LEFT,
    .communication_format = I2S_COMM_FORMAT_STAND_I2S,
    .intr_alloc_flags = ESP_INTR_FLAG_LEVEL1,
    .dma_buf_count = 8,
    .dma_buf_len = 256
  };
  i2s_pin_config_t pins = {
    .bck_io_num = I2S_SCK, .ws_io_num = I2S_WS,
    .data_out_num = I2S_PIN_NO_CHANGE, .data_in_num = I2S_SD
  };
  i2s_driver_install(I2S_PORT, &cfg, 0, NULL);
  i2s_set_pin(I2S_PORT, &pins);
}

void micReadTask(void*) {
  int32_t raw[256];
  size_t bytesRead;
  for (;;) {
    i2s_read(I2S_PORT, raw, sizeof(raw), &bytesRead, portMAX_DELAY);
    // raw samples are 32-bit, real audio data is the top 24 bits — shift down
    for (int i = 0; i < bytesRead / 4; i++) {
      int32_t sample = raw[i] >> 8;
      writeToRingBuffer(sample);
    }
  }
}
```

---

## 4. Speaker Output — Physical & Code

### Physically
The **MAX98357A** is a Class-D amplifier with a built-in I2S DAC. Class-D means it doesn't linearly amplify the signal (like Class-A/AB) — it converts the digital audio into a high-frequency **PWM (pulse-width modulation)** signal whose duty cycle tracks the waveform, then switches a power transistor fully on/off at that duty cycle. An LC filter (often just the speaker coil's own inductance) smooths this into an analog waveform. This is why Class-D is so efficient (>90%) and stays cool — the transistors are never in a lossy "partially on" state.

The speaker itself is a standard **electrodynamic driver**: a voice coil attached to a diaphragm sits in the field of a permanent magnet. Current through the coil creates a varying magnetic field that pushes/pulls against the magnet, moving the diaphragm and displacing air — that's the sound.

### Wiring
| MAX98357A pin | ESP32 pin |
|---|---|
| VIN | 5V (or 3.3V, lower volume) |
| GND | GND |
| DIN | GPIO22 |
| BCLK | GPIO27 |
| LRC | GPIO14 |
| SD (shutdown, active high enables) | GPIO21 |
| Speaker + / − | Speaker terminals |

Use a **second I2S port** (`I2S_NUM_1`) for playback so mic and speaker never contend for the same bus.

### Code
```cpp
i2s_config_t out_cfg = {
  .mode = (i2s_mode_t)(I2S_MODE_MASTER | I2S_MODE_TX),
  .sample_rate = SAMPLE_RATE,
  .bits_per_sample = I2S_BITS_PER_SAMPLE_16BIT,
  .channel_format = I2S_CHANNEL_FMT_ONLY_LEFT,
  .communication_format = I2S_COMM_FORMAT_STAND_I2S,
  .dma_buf_count = 8, .dma_buf_len = 256
};
i2s_driver_install(I2S_NUM_1, &out_cfg, 0, NULL);
i2s_set_pin(I2S_NUM_1, &out_pins);

void playbackTask(void*) {
  int16_t buf[256];
  for (;;) {
    size_t n = readFromFileOrBuffer(buf, sizeof(buf));
    size_t written;
    i2s_write(I2S_NUM_1, buf, n, &written, portMAX_DELAY);
  }
}
```

---

## 5. Storage — Physical & Code

### Physically
A microSD card is **NAND flash memory** — data is stored as trapped charge in floating-gate transistors, read by sensing threshold voltage shifts. The card exposes an SPI (or faster SDIO) interface with an onboard controller that handles wear-leveling and the FAT filesystem block layer, so from the MCU's side it just looks like a block storage device you talk to over SPI.

### Wiring (SPI mode)
| microSD module | ESP32 pin |
|---|---|
| CS | GPIO5 |
| MOSI | GPIO23 |
| MISO | GPIO19 |
| SCK | GPIO18 |
| VCC | 3.3V |
| GND | GND |

### Code
Audio is written as a standard **WAV file**: a 44-byte header (RIFF chunk descriptor + fmt subchunk + data subchunk) followed by raw PCM samples. You write a placeholder header, stream samples, then seek back and patch the header's size fields once recording stops (since you don't know the final length in advance).

```cpp
#include <SD.h>
#include <SPI.h>

File audioFile;

void startRecording(const char* filename) {
  audioFile = SD.open(filename, FILE_WRITE);
  writeWavHeaderPlaceholder(audioFile); // 44 bytes, sizes = 0 for now
}

void onAudioChunk(int16_t* samples, size_t count) {
  audioFile.write((uint8_t*)samples, count * 2);
}

void stopRecording() {
  uint32_t dataSize = audioFile.size() - 44;
  audioFile.seek(4);
  writeLE32(audioFile, dataSize + 36);   // RIFF chunk size
  audioFile.seek(40);
  writeLE32(audioFile, dataSize);        // data chunk size
  audioFile.close();
}
```

---

## 6. The Motorized Tape Reel — Physical & Code (the signature mechanism)

This is the part that makes a TP-7 feel like a TP-7, and it's worth understanding precisely: **it isn't moving physical tape.** It's a free-spinning wheel, instrumented with a rotary sensor, that a small motor can also drive. It functions simultaneously as:
- a **scrub wheel** (you turn it, playback position jumps)
- a **jog dial** (menu navigation)
- a **visual/haptic status indicator** (it spins on its own during record/playback, and you can feel it resist or stop under your finger)

### Physically — sensing rotation
A small **diametrically-magnetized magnet** (north/south poles across its diameter, not top/bottom) is glued to the reel's center shaft. Below it sits the **AS5600**, a Hall-effect angle sensor. Hall-effect sensing works because the magnetic field from the rotating magnet, sensed by an array of Hall elements on the AS5600 die, changes its measured *angle* (not just its strength) as the magnet rotates — the chip's internal DSP computes the arctangent of the field vector components and outputs an absolute 12-bit angle (0–4095, i.e., 0.088°/count) over I2C. Absolute means it always knows the exact angle immediately at power-on, no homing/calibration pass needed like an incremental encoder.

### Physically — driving rotation
The **N20 micro gearmotor** is a small brushed DC motor with an integrated gearbox (typically ~50:1 to ~1000:1 reduction, pick a slower ratio like 100:1 for smooth, low-speed torque). Current through the motor's windings creates a magnetic field that interacts with fixed magnets in the motor housing, producing torque on the rotor; the gearbox trades speed for torque so it can move the reel smoothly rather than spinning too fast to look tape-like.

The **DRV8833** is a dual H-bridge driver: four transistors arranged so current can flow through the motor in either direction depending on which pair is switched on, giving you forward/reverse. Speed is controlled via **PWM** on the enable/input lines — the average voltage the motor "feels" is proportional to the PWM duty cycle.

### Wiring
| Component | ESP32 pin |
|---|---|
| AS5600 VCC | 3.3V |
| AS5600 GND | GND |
| AS5600 SDA | GPIO21 |
| AS5600 SCL | GPIO22 |
| DRV8833 AIN1 | GPIO18 |
| DRV8833 AIN2 | GPIO19 |
| DRV8833 VM | Battery+ (3.7–5V) |
| DRV8833 AOUT1/2 | Motor terminals |

*(Note: AS5600 and SD card share I2C/SPI address space but different buses — if GPIO18/19 collide with your SD wiring, remap either the SD CS/SCK or motor driver pins; ESP32 GPIOs are largely reassignable in software.)*

### Code — reading the reel for scrubbing
```cpp
#include <Wire.h>
#define AS5600_ADDR 0x36
#define ANGLE_REG   0x0C

uint16_t readReelAngle() {
  Wire.beginTransmission(AS5600_ADDR);
  Wire.write(ANGLE_REG);
  Wire.endTransmission(false);
  Wire.requestFrom(AS5600_ADDR, 2);
  uint16_t angle = (Wire.read() << 8) | Wire.read();
  return angle & 0x0FFF; // 12-bit
}

int32_t lastAngle = 0;
int32_t audioPositionSamples = 0;
const float SAMPLES_PER_DEGREE = SAMPLE_RATE * 0.05; // tune: ~50ms of audio per degree of turn

void scrubTask(void*) {
  for (;;) {
    int32_t angle = readReelAngle();
    int32_t delta = angle - lastAngle;
    // handle 0/4095 wrap-around
    if (delta > 2048) delta -= 4096;
    if (delta < -2048) delta += 4096;

    if (userIsTouchingReel()) {
      audioPositionSamples += delta * SAMPLES_PER_DEGREE;
      seekPlayback(audioPositionSamples);
    }
    lastAngle = angle;
    vTaskDelay(pdMS_TO_TICKS(2)); // ~500Hz poll rate
  }
}
```

`userIsTouchingReel()` in the real device is inferred from sudden deceleration/resistance; a simple DIY approach is a small capacitive-touch pad (ESP32 has native touch-sensing pins) on the reel's rim, or just detecting when angle changes faster than the motor's own commanded speed (meaning an external hand is overriding it).

### Code — driving the motor to spin during playback
```cpp
void driveMotor(int pwmDuty /* -255..255, sign = direction */) {
  if (pwmDuty >= 0) {
    ledcWrite(PWM_CHANNEL_A, pwmDuty);
    ledcWrite(PWM_CHANNEL_B, 0);
  } else {
    ledcWrite(PWM_CHANNEL_A, 0);
    ledcWrite(PWM_CHANNEL_B, -pwmDuty);
  }
}

void motorTask(void*) {
  for (;;) {
    if (isPlaying && !userIsTouchingReel()) {
      driveMotor(80); // gentle constant spin during playback
    } else if (!isPlaying) {
      driveMotor(0);
    }
    vTaskDelay(pdMS_TO_TICKS(20));
  }
}
```

---

## 7. Buttons & Rocker — Physical & Code

### Physically
Tactile buttons are simple momentary SPST switches — a conductive dome collapses under pressure to bridge two contacts, pulling a GPIO pin from HIGH (via an internal pull-up resistor) to LOW. Mechanical contacts "bounce" for a few milliseconds when pressed (the metal contacts physically vibrate before settling), so software debouncing is required or you'll register multiple presses per click.

The scrub rocker is just two of these switches under a single seesaw-shaped cap — pressing the top edge closes one contact (fast-forward), pressing the bottom closes the other (rewind).

### Wiring
| Button | ESP32 pin |
|---|---|
| Record/Memo | GPIO32 |
| Play/Stop | GPIO27 (reused if not driving amp LRC on same pin — remap as needed) |
| Mode | GPIO35 |
| Rocker FF | GPIO34 |
| Rocker RW | GPIO39 |

All wired: one leg to GPIO, other leg to GND, using `INPUT_PULLUP` mode internally.

### Code
```cpp
struct Button { uint8_t pin; bool lastState; uint32_t lastChange; };
Button recordBtn = {32, HIGH, 0};

void pollButton(Button &b, void (*onPress)()) {
  bool state = digitalRead(b.pin);
  if (state != b.lastState && millis() - b.lastChange > 30) { // 30ms debounce
    b.lastChange = millis();
    b.lastState = state;
    if (state == LOW) onPress(); // active-low
  }
}

void loop() {
  pollButton(recordBtn, toggleRecording);
  // ...repeat for other buttons
}
```

---

## 8. External I/O Jacks & Codec — Physical & Code

### Physically
A **TRRS jack** has 4 contacts (Tip, Ring, Ring, Sleeve), letting one 3.5mm connector carry stereo in + mono mic, or be reconfigured as two-way I/O like the real TP-7's jacks. To use these at *line level* (not just direct-to-MCU digital mic level), you need a proper **audio codec chip** like the WM8960, which contains real analog-domain ADCs/DACs, programmable gain amplifiers, and analog switching — because raw GPIO/I2S from the ESP32 can't safely accept the wider voltage swings and impedances of external pro/consumer audio gear.

The codec is controlled two ways simultaneously:
- **I2C** — a low-speed control bus to set gain, routing, and mode registers
- **I2S** — the actual high-speed audio sample stream

### Wiring
| WM8960 pin | ESP32 pin |
|---|---|
| SDA/SCL | GPIO21/GPIO22 (shared I2C bus with AS5600 — different address, fine) |
| I2S BCLK/WS/DOUT/DIN | dedicated I2S port pins |
| VDD | 3.3V |

### Code (register config is codec-specific; conceptually)
```cpp
// I2C register writes to configure input gain, routing, output mode
wm8960_write(0x00, 0x0197); // Left input volume
wm8960_write(0x02, 0x0179); // Left output volume
wm8960_write(0x1A, 0x0008); // Route line-in -> ADC
// Then treat its I2S stream exactly like the internal mic's
```

---

## 9. USB-C — Charging & Data

### Physically
USB-C is just a connector standard with 24 pins supporting multiple *protocols* over the same physical port. For this project you need exactly two of its capabilities:
1. **VBUS power delivery** (5V, or negotiated higher via CC-line resistors) — for charging.
2. **USB Mass Storage / Audio Class** — for data.

The **TP4056** charge controller monitors battery voltage and regulates charge current in two phases: constant-current (bulk charging, until cell reaches ~4.2V) then constant-voltage (float charging, current tapers off) — this two-stage profile is standard for all LiPo chemistry and prevents overcharging, which can otherwise cause thermal runaway.

### Simplification for DIY builds
Getting full USB Audio Class 2.0 working on ESP32 firmware is a deep rabbit hole (it doesn't have native high-speed USB on most variants). Two practical paths:
- **Easiest:** expose the SD card as a **USB Mass Storage Device** via TinyUSB — drag files off like a USB flash drive, and use your phone's own mic recorder + a separate transcription app instead of true USB audio streaming.
- **Full-featured:** use an **ESP32-S3** (native USB OTG) with TinyUSB's UAC (USB Audio Class) driver for true "shows up as an audio interface" behavior like the real TP-7.

### Wiring
| TP4056 | Connection |
|---|---|
| IN+/IN− | USB-C VBUS/GND |
| BAT+/BAT− | LiPo cell |
| OUT+/OUT− | System power rail → ESP32 VIN (via a boost/buck as needed) |

---

## 10. Bluetooth & Transcription

### Physically
The ESP32's radio does the same digital-to-RF conversion any Bluetooth chip does: your audio/data bytes are chunked into packets, spread across the 2.4GHz ISM band's 79 channels via frequency-hopping spread spectrum, modulated (GFSK), and broadcast.

### Code
Two options depending on features desired:
- **BLE file transfer**: send the finished WAV file to a phone app as byte chunks over a GATT characteristic once recording stops.
- **A2DP source**: stream live audio continuously (more power-hungry, more complex).

For transcription itself — that's not a physical/firmware component at all, it's a network API call the *phone app* makes to a speech-to-text service after receiving the audio. The device's job ends at getting bytes to the phone.

```cpp
#include <BLEDevice.h>
#include <BLEServer.h>

void sendFileOverBLE(File &f) {
  uint8_t chunk[512];
  while (f.available()) {
    size_t n = f.read(chunk, sizeof(chunk));
    pCharacteristic->setValue(chunk, n);
    pCharacteristic->notify();
    vTaskDelay(pdMS_TO_TICKS(10)); // pace to avoid overrunning BLE MTU/throughput
  }
}
```

---

## 11. Power Budget & Battery Life

| Subsystem | Typical draw |
|---|---|
| ESP32 active (WiFi/BT off) | ~40 mA |
| ESP32 with BLE active | ~100–130 mA |
| INMP441 mic | ~1.4 mA |
| MAX98357A (playing, moderate volume) | ~100–500 mA |
| N20 motor (light load) | ~50–150 mA |
| SD card write | ~30–100 mA (bursty) |

Rough continuous-recording draw (mic + SD + MCU, no BT, no motor): **~120 mA** → a 500mAh cell gives **~4 hours**; scale battery capacity up (1000mAh+) to approach the real device's 7-hour spec, remembering to size your enclosure accordingly.

---

## 12. Firmware Task Architecture (put it all together)

```cpp
void setup() {
  micInit(); speakerInit(); sdInit(); i2cInit();
  motorInit(); buttonsInit(); bleInit();

  xTaskCreatePinnedToCore(audioRecordTask, "rec",  4096, NULL, 3, NULL, 1);
  xTaskCreatePinnedToCore(audioPlaybackTask,"play", 4096, NULL, 3, NULL, 1);
  xTaskCreatePinnedToCore(scrubTask,        "scrub",2048, NULL, 2, NULL, 0);
  xTaskCreatePinnedToCore(motorTask,        "motor",2048, NULL, 2, NULL, 0);
  xTaskCreatePinnedToCore(uiTask,           "ui",   2048, NULL, 1, NULL, 0);
}
```
Audio tasks get **higher priority** and live on **core 1** exclusively, since a missed I2S DMA deadline causes audible glitches. UI/motor/button polling lives on **core 0**, where occasional millisecond-scale jitter is imperceptible.

---

## 13. Build Order (recommended)

1. **Audio core first**: mic → SD → WAV file → speaker playback, no motor, no buttons except a hardcoded record/stop via serial console. Get clean audio round-tripping before anything else.
2. **Add buttons**: physical record/play/stop.
3. **Add the encoder + motor as a pure UI layer** on top of already-working playback — map angle deltas to seek offsets.
4. **Add the codec + TRRS jacks** for external mic/line-level I/O.
5. **Add BLE file transfer** last, since it's fully decoupled from the rest.
6. **Enclosure + reel machining** — a 3D-printed reel hub press-fit onto the N20 motor shaft, with the AS5600 magnet embedded in the center, sitting just above the sensor on the PCB.

---

## 14. Key Differences From the Real TP-7 (so expectations are calibrated)

- Real TP-7 uses a **custom brushless motor with ball bearings** for a smoother, silent reel feel — an N20 brushed gearmotor will have more mechanical noise and cogging.
- Real device does **on-device DSP** for the VU meter, multi-channel mixing, and 24-bit/96kHz — this guide targets 16-bit/44.1kHz, which is CD-quality and plenty for voice/most music demos, but not matching their pro-audio spec.
- True **USB Audio Class 2.0 multi-channel interface** mode requires an ESP32-S3 (or dedicated USB audio codec IC) — plain ESP32-WROOM can't natively present as a multichannel USB audio device.
- Aluminum unibody vs. 3D-printed shell is obviously a fit-and-finish gap, not a functional one.

---

## 15. Reference Component Datasheets to Pull Up While Building

- INMP441 I2S MEMS microphone datasheet
- MAX98357A I2S Class-D amplifier datasheet
- AS5600 magnetic rotary position sensor datasheet
- DRV8833 dual H-bridge motor driver datasheet
- WM8960 audio codec datasheet
- TP4056 linear Li-ion battery charger datasheet
- ESP32 Technical Reference Manual (I2S, I2C, SPI, PWM/LEDC peripheral chapters)

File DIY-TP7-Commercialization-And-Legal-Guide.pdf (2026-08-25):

# HARDWARE COMMERCIALIZATION & LEGAL COMPLIANCE GUIDE

## A Comprehensive Legal, Regulatory, Intellectual Property & Manufacturing Blueprint for Selling a Motorized-Reel Field Recorder

Author: Product Architecture & Regulatory Advisory Team | Project: DIY TP-7 Digital Twin & Hardware Platform |
Classification: Confidential Strategy

EXECUTIVE SUMMARY & CRITICAL WARNING:
Transitioning a DIY electronics project into a commercial consumer hardware product involves navigating strict intellectual property protections (trade dress, patents, trademarks), mandatory wireless certifications (FCC, CE, UKCA), lithium battery transport regulations (UN 38.3), and strict product liability insurance requirements. Building a functional prototype is ~15% of the effort; 85% of commercialization cost resides in DFM, regulatory compliance, supply chain scaling, and legal de-risking.

## 1. Intellectual Property (IP) & Legal Pitfalls (Teenage Engineering IP)

When commercializing hardware inspired by an existing market leader (such as Teenage Engineering's TP-7), you must navigate four distinct categories of Intellectual Property law. Infringement in any of these areas can result in immediate Cease-and-Desist letters, customs asset seizures, and statutory damages.

### A. Trademark Infringement & Brand Protection (Absolute Prohibition)

- Forbidden Terms: You cannot use 'TP-7', 'Teenage Engineering', 'Field System', 'TX-6', 'OP-1', or similar trademarks in product names, domain names, packaging, promotional media, or metadata. Doing so constitutes direct trademark infringement under the Lanham Act (15 U.S.C. § 1114).
- Permitted Comparative Statements: You may only state 'Compatible with TRRS audio accessories' or 'Alternative motorized field recorder'. Do not describe the product as a 'TP-7 Clone' or 'DIY TP-7 Commercial Replica'.
- Independent Branding: You must create an original brand name (e.g., 'SpoolCorder Pro', 'PulseReel 7') and register standard word and design marks with the USPTO / EUIPO.

### B. Trade Dress & Design Patents (Aesthetic Form Factor)

Trade dress protects the overall visual appearance and consumer recognition of a product. Teenage Engineering is renowned for aggressively defending its iconic design language (anodized aluminum unibody, specific circular spool proportion, distinct orange recessed buttons, minimalist chamfered geometry).
- Design Differentiation Checklist:
1. Modify the exterior chassis dimensions and corner radiuses (avoid exact 1:1 aspect ratio replication).
2. Use a distinct button layout and alternative accent colorways (e.g., cobalt blue or anodized brass instead of iconic TE orange).
3. Re-engineer the tape reel hub design (e.g., 4-spoke or 5-spoke geometry rather than the signature 3-spoke TE spool cutouts).
CONFIDENTIAL & PROPRIETARY | COMMERCIAL HARDWARE COMPLIANCE GUIDE | Page 1 of 4

### C. Utility Patents & Mechanical Claims (Touch-to-Pause & Scrub Mechanisms)

Teenage Engineering holds patents on motorized haptic jog dials, magnetic slip clutches, and tactile shuttle rockers. To avoid utility patent infringement:
- Prior Art Search: Perform a thorough FTO (Freedom-to-Operate) patent search via Google Patents and Espacenet covering classification codes G11B (Recording/Playback) and H04R (Audio Transducers).
- Algorithmic Distinction: Use software-based Hall sensor angular differentiation (detecting velocity drop on the AS5600) rather than proprietary mechanical brake clutch hardware.

## 2. Mandatory Regulatory Compliance & Certifications

Selling electronic hardware legally requires passing standardized electromagnetic compatibility (EMC) and radio frequency (RF) testing. Shipping uncertified hardware carries civil fines of up to $25,000 per violation day.

Certification / Region | Requirement & Scope | Testing Cost (Est.) | Modular Strategy
FCC (USA) Part 15 Class B | Electromagnetic emissions & intentional RF broadcast (Bluetooth / BLE). | $2,500 – $4,500 (Modular) $12,000 – $18,000 (Full) | Use pre-certified ESP32-WROOM-32E (FCC ID: 2AC7Z-ESPWROOM32E) to bypass full intentional radiator RF testing.
CE Marking (EU) RED, EMC, RoHS | Radio Equipment Directive (2014/53/EU), EMC Directive, and RoHS 3 hazardous substance restrictions. | €4,000 – €7,500 | Requires Declaration of Conformity (DoC), Technical Construction File (TCF), and lead-free ENIG PCB fabrication.
UKCA (UK) | UK Radio Equipment Regulations post-Brexit. | £1,500 – £3,000 | Direct alignment with CE test reports with UKCA technical file.
ISED / IC (Canada) | Innovation, Science and Economic Development Canada (RSS-247). | $1,800 – $3,000 | ESP32 module carries Canadian IC pre-certification.

## 3. Lithium Battery Safety, Transport & Environmental Laws

Lithium-Polymer (LiPo) batteries are classified as Dangerous Goods (Class 9). Commercial sale and shipping requires strict compliance to prevent thermal runaway fires.

- UN 38.3 Transport Certification: Required by all air (IATA/ICAO) and ground carriers (USPS, FedEx, DHL) for shipping devices containing integrated lithium batteries. Testing subjects cells to altitude simulation, thermal shock, vibration, impact, and external short-circuiting.
- Dual Protection Hardware: Commercial boards must feature an integrated battery protection IC (e.g., DW01A or Texas Instruments BQ24075) with over-voltage, under-voltage, over-current, and NTC thermistor temperature sensing to halt charging if battery exceeds 45°C.
- WEEE & California Proposition 65: Must include the crossed-out wheelie bin symbol on packaging and mandatory chemical exposure warning labels if lead or specific phthalates are present.
COMMERCIALIZATION, REGULATORY & LEGAL BLUEPRINT | DIY TP-7 MOTORIZED RECORDER
CONFIDENTIAL & PROPRIETARY | COMMERCIAL HARDWARE COMPLIANCE GUIDE | Page 2 of 4

## 4. Software, Firmware & Audio Codec Licensing

- Open-Source License Segregation: The ESP32 ESP-IDF framework is distributed under Apache 2.0 (permissive for commercialization). However, ensure no GPL v3.0 libraries are statically linked into your production firmware, which could legally obligate you to release your proprietary firmware source code to customers.
- Audio Codec Patent Pools: Uncompressed 16/24-bit Linear PCM (.WAV) and FLAC are royalty-free. If you implement compressed recording (MP3 or AAC), you must verify licensing terms with patent pools (Via Licensing Alliance). Recording uncompressed WAV is standard for pro field recorders and completely avoids patent royalty overhead.

## 5. Manufacturing Economics, DFM & Target Unit Pricing

A healthy hardware business relies on the Hardware Multiplier Rule: Retail Price (MSRP) must be 3.5x to 4.5x the Bill of Materials (BOM) cost to cover manufacturing scrap, tooling amortization, logistics, warranty reserves, and retail channel margins.

Cost Component | Batch 50 Units (DIY) | Batch 1,000 Units (Pilot) | Batch 10,000 Units (Scale)
Electronics BOM (ESP32, Mic, Codec, Motor, Sensors) | $38.50 | $22.40 | $14.80
PCB Fabrication + SMT Assembly (JLCPCB/PCBWay) | $18.00 | $7.50 | $3.80
Enclosure & Mechanism (CNC Aluminum / Tooling) | $24.00 (MJF 3D) | $16.50 (CNC) | $6.20 (Die-Cast / Anodized)
Battery (1000mAh UN38.3 Certified) | $6.50 | $3.80 | $2.40
Packaging, USB-C Cable & Manuals | $4.00 | $2.80 | $1.60
Total Unit COGS (Cost of Goods Sold) | $91.00 | $53.00 | $28.80
Target Retail Price (MSRP) | $249.00 (2.7x) | $199.00 (3.8x) | $129.00 (4.5x)

## 6. Product Liability, Warranties & Insurance

- Commercial General & Product Liability Insurance: Obtain at least $1,000,000 to $2,000,000 in product liability coverage before shipping any consumer electronics with lithium-ion batteries.
- Limited 1-Year Consumer Warranty: Draft clear warranty terms excluding unauthorized teardowns, water damage, or excessive motor torque abuse.
- RMA (Return Merchandise Authorization) Reserve: Budget 3% to 5% of gross revenue for warranty replacements, field returns, and component failure triage.
CONFIDENTIAL & PROPRIETARY | COMMERCIAL HARDWARE COMPLIANCE GUIDE | Page 3 of 4

## 7. Actionable Commercialization Checklist

Phase | Action Item | Status
1. Legal | Trademark original brand name (USPTO/EUIPO) & verify trade dress clearance. | [ ] Required
2. Engineering | Freeze 4-layer custom PCB design with pre-certified ESP32-WROOM-32E module. | [ ] Required
3. Battery Safety | Source UN 38.3 and IEC 62133 certified LiPo cells with onboard NTC protection. | [ ] Required
4. Regulatory | Submit 3 pilot units to accredited test lab for FCC Part 15 / CE RED emissions testing. | [ ] Required
5. Insurance | Bind commercial product liability policy with hardware e-commerce rider. | [ ] Required
6. Packaging | Print FCC ID, CE logo, WEEE bin symbol, and ratings on rear chassis laser etching. | [ ] Required
CONFIDENTIAL & PROPRIETARY | COMMERCIAL HARDWARE COMPLIANCE GUIDE | Page 4 of 4

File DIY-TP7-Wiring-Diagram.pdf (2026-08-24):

# DIY TP-7 — Master Wiring / Block Diagram

ESP32-WROOM core | I2S audio path | I2C sensor/codec bus | SPI storage | motor + button GPIO

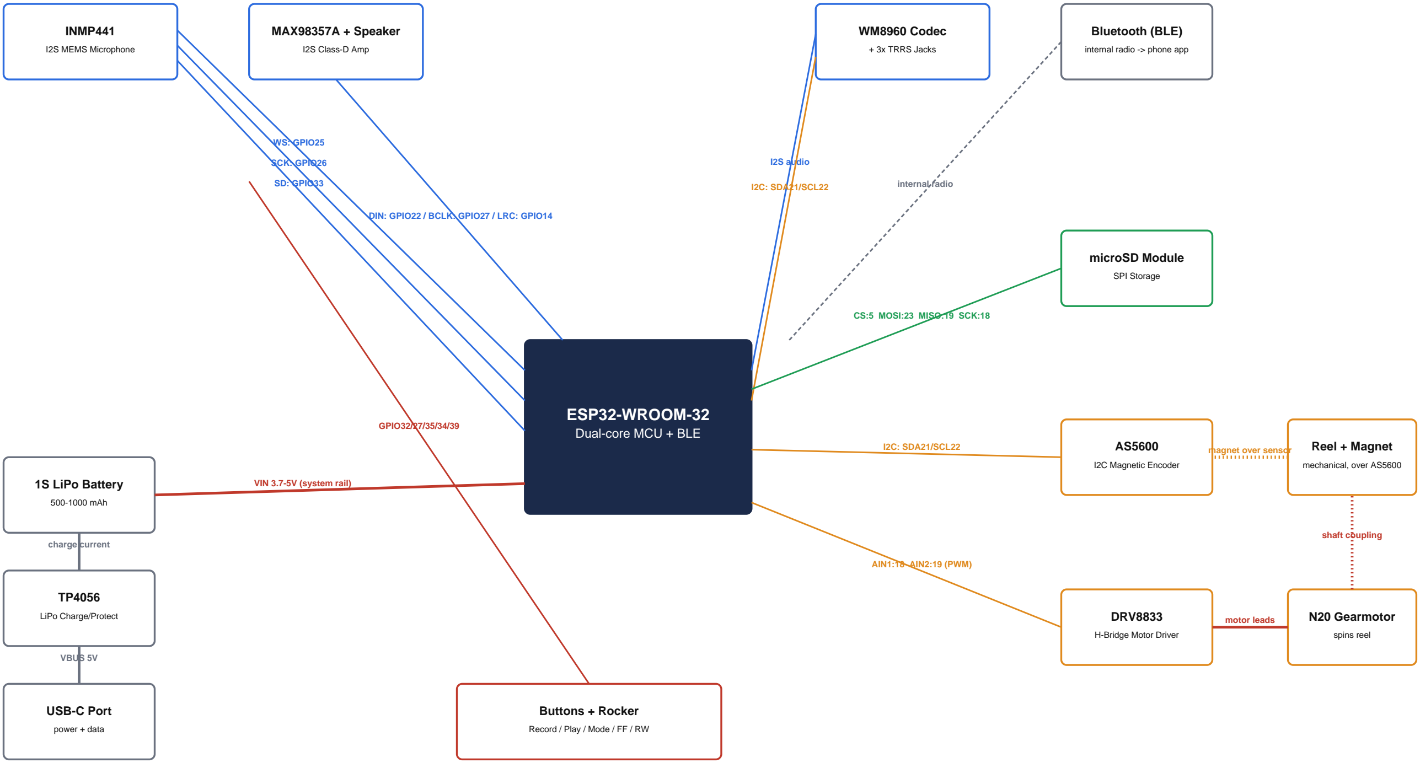
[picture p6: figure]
ESP32-WROOM-32 Dual-core MCU + BLE; INMP441; I2S MEMS Microphone; MAX98357A + Speaker; I2S Class-D Amp; WM8960 Codec; + 3x TRRS Jacks; Bluetooth (BLE); internal radio -> phone app; microSD Module; SPI Storage; I2C Magnetic Encoder; Reel + Magnet; mechanical, over AS5600; DRV8833; H-Bridge Motor Driver; N20 Gearmotor; spins reel; Buttons + Rocker; Record / Play / Mode / FF / RW; USB-C Port; power + data; LiPo Charge/Protect; 1S LiPo Battery; 500-1000 mAh; WS: GPIO25; SCK: GPIO26; SD: GPIO33; I2S audio; I2C: SDA21/SCL22; internal radio; CS:5 MOSI:23 MISO:19 SCK:18; magnet over sensor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

DIN: GPIO22 / BCLK: GPIO27 / LRC: GPIO14

## Legend:

I2S audio bus | I2C bus / motor GPIO | SPI (storage) | power / motor leads / buttons | power supply chain / radio

Pin numbers are ESP32 GPIO references from the DIY TP-7 Build Guide — remap as needed to resolve any physical routing conflicts on your board.

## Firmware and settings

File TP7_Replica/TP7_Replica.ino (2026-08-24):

/*
  DIY TP-7 Motorized-Reel Field Recorder Firmware (v2.0)
  Inspired by the Teenage Engineering TP-7 Field Recorder Architecture

  Subsystems:
  - Dual-Core FreeRTOS Partitioning (Core 1: 44.1kHz I2S Audio DMA, Core 0: 500Hz UI & Motor Control)
  - AS5600 12-Bit Contactless Magnetic Angle Sensor (Scrubbing, Jog Dial & Touch-to-Pause Stall Sensing)
  - DRV8833 Dual H-Bridge Motor Driver with LEDC PWM Speed Control
  - INMP441 Digital MEMS Microphone (I2S_NUM_0 Master RX)
  - MAX98357A Class-D DAC/Amp (I2S_NUM_1 Master TX)
  - MicroSD FAT32 High-Throughput WAV Streamer
  - 2-Stage Side Rocker Switch (Variable-Speed Shuttle Scrub)
  - Dedicated Memo Mode (Hold-to-Record Quick Voice Memos)
  - BLE Companion App GATT Audio & Transcription Broadcast
*/

#include <Arduino.h>
#include <driver/i2s.h>
#include <SD.h>
#include <SPI.h>
#include <Wire.h>
#include <BLEDevice.h>
#include <BLEServer.h>
#include <BLEUtils.h>
#include <BLE2902.h>

// ==========================================
// 1. PIN DEFINITIONS & CONSTANTS
// ==========================================
#define SAMPLE_RATE         44100
#define BITS_PER_SAMPLE     16
#define I2S_DMA_BUF_LEN     256
#define I2S_DMA_BUF_COUNT   8

// INMP441 I2S Microphone (I2S_NUM_0)
#define PIN_I2S_MIC_WS      25
#define PIN_I2S_MIC_SCK     26
#define PIN_I2S_MIC_SD      33

// MAX98357A I2S Amplifier (I2S_NUM_1)
#define PIN_I2S_SPK_DIN     22
#define PIN_I2S_SPK_BCLK    27
#define PIN_I2S_SPK_LRC     14

// I2C Bus (AS5600 & SSD1306 OLED)
#define PIN_I2C_SDA         21
#define PIN_I2C_SCL         15
#define AS5600_I2C_ADDR     0x36
#define AS5600_REG_ANGLE    0x0C

// DRV8833 Motor Driver (PWM LEDC Channels 0 & 1)
#define PIN_MOTOR_IN1       18
#define PIN_MOTOR_IN2       19
#define PWM_MOTOR_CH_A      0
#define PWM_MOTOR_CH_B      1
#define PWM_MOTOR_FREQ      20000
#define PWM_MOTOR_RES       8 // 8-bit (0-255)

// MicroSD SPI Bus
#define PIN_SD_CS           5
#define PIN_SD_MOSI         23
#define PIN_SD_MISO         12
#define PIN_SD_SCK          13

// Hardware Buttons & Rocker Switch
#define PIN_BTN_REC         32 // Record Toggle
#define PIN_BTN_MEMO        34 // Instant Memo (Hold-to-record)
#define PIN_BTN_PLAY        35 // Play / Pause
#define PIN_BTN_MODE        36 // Mode / Settings
#define PIN_ROCKER_FWD      39 // Rocker Fast-Forward
#define PIN_ROCKER_REW      4  // Rocker Rewind
#define PIN_LED_REC         2  // Status LED

// ==========================================
// 2. DATA STRUCTURES & SYSTEM STATE
// ==========================================
enum DeviceMode {
  MODE_FIELD_REC,
  MODE_MEMO_STT,
  MODE_USB_AUDIO,
  MODE_MULTI_TRACK
};

struct DeviceState {
  volatile bool isPlaying;
  volatile bool isRecording;
  volatile bool isMemoActive;
  volatile bool isTouchPaused;     // TE TP-7 signature touch-to-pause
  volatile int32_t currentSamplePos;
  volatile int32_t totalSamples;
  volatile float scrubSpeedScale;  // Variable speed scaling
  DeviceMode currentMode;
  uint16_t lastAngle;
  int16_t angularVelocity;
  uint32_t fileIndex;
};

DeviceState sysState = {
  false, false, false, false, 0, 0, 1.0f, MODE_FIELD_REC, 0, 0, 1
};

// Double Audio Ring Buffer
#define RING_BUF_SIZE 4096
int16_t audioRingBuf[RING_BUF_SIZE];
volatile size_t ringWritePtr = 0;
volatile size_t ringReadPtr = 0;
portMUX_TYPE ringBufferMutex = portMUX_INITIALIZER_UNLOCKED;

File activeAudioFile;
BLECharacteristic *pBleCharacteristic = nullptr;

// ==========================================
// 3. HARDWARE DRIVER INITIALIZATION
// ==========================================
void initMicrophone() {
  i2s_config_t micCfg = {
    .mode = (i2s_mode_t)(I2S_MODE_MASTER | I2S_MODE_RX),
    .sample_rate = SAMPLE_RATE,
    .bits_per_sample = I2S_BITS_PER_SAMPLE_32BIT, // INMP441 outputs 24b in 32b frame
    .channel_format = I2S_CHANNEL_FMT_ONLY_LEFT,
    .communication_format = I2S_COMM_FORMAT_STAND_I2S,
    .intr_alloc_flags = ESP_INTR_FLAG_LEVEL1,
    .dma_buf_count = I2S_DMA_BUF_COUNT,
    .dma_buf_len = I2S_DMA_BUF_LEN,
    .use_apll = true
  };
  i2s_pin_config_t micPins = {
    .bck_io_num = PIN_I2S_MIC_SCK,
    .ws_io_num = PIN_I2S_MIC_WS,
    .data_out_num = I2S_PIN_NO_CHANGE,
    .data_in_num = PIN_I2S_MIC_SD
  };
  i2s_driver_install(I2S_NUM_0, &micCfg, 0, NULL);
  i2s_set_pin(I2S_NUM_0, &micPins);
}

void initSpeaker() {
  i2s_config_t spkCfg = {
    .mode = (i2s_mode_t)(I2S_MODE_MASTER | I2S_MODE_TX),
    .sample_rate = SAMPLE_RATE,
    .bits_per_sample = I2S_BITS_PER_SAMPLE_16BIT,
    .channel_format = I2S_CHANNEL_FMT_ONLY_LEFT,
    .communication_format = I2S_COMM_FORMAT_STAND_I2S,
    .intr_alloc_flags = ESP_INTR_FLAG_LEVEL1,
    .dma_buf_count = I2S_DMA_BUF_COUNT,
    .dma_buf_len = I2S_DMA_BUF_LEN,
    .use_apll = true
  };
  i2s_pin_config_t spkPins = {
    .bck_io_num = PIN_I2S_SPK_BCLK,
    .ws_io_num = PIN_I2S_SPK_LRC,
    .data_out_num = PIN_I2S_SPK_DIN,
    .data_in_num = I2S_PIN_NO_CHANGE
  };
  i2s_driver_install(I2S_NUM_1, &spkCfg, 0, NULL);
  i2s_set_pin(I2S_NUM_1, &spkPins);
}

void initMotor() {
  ledcSetup(PWM_MOTOR_CH_A, PWM_MOTOR_FREQ, PWM_MOTOR_RES);
  ledcSetup(PWM_MOTOR_CH_B, PWM_MOTOR_FREQ, PWM_MOTOR_RES);
  ledcAttachPin(PIN_MOTOR_IN1, PWM_MOTOR_CH_A);
  ledcAttachPin(PIN_MOTOR_IN2, PWM_MOTOR_CH_B);
}

void setMotorDrive(int16_t dutyCycle /* -255 to 255 */) {
  if (dutyCycle > 0) {
    ledcWrite(PWM_MOTOR_CH_A, (uint32_t)dutyCycle);
    ledcWrite(PWM_MOTOR_CH_B, 0);
  } else if (dutyCycle < 0) {
    ledcWrite(PWM_MOTOR_CH_A, 0);
    ledcWrite(PWM_MOTOR_CH_B, (uint32_t)(-dutyCycle));
  } else {
    ledcWrite(PWM_MOTOR_CH_A, 0);
    ledcWrite(PWM_MOTOR_CH_B, 0);
  }
}

uint16_t readAS5600Angle() {
  Wire.beginTransmission(AS5600_I2C_ADDR);
  Wire.write(AS5600_REG_ANGLE);
  if (Wire.endTransmission(false) != 0) return 0;
  Wire.requestFrom(AS5600_I2C_ADDR, (uint8_t)2);
  if (Wire.available() >= 2) {
    uint16_t angle = (Wire.read() << 8) | Wire.read();
    return angle & 0x0FFF; // 12-bit (0-4095)
  }
  return 0;
}

// ==========================================
// 4. CORE 1 AUDIO TASK (High Real-Time Priority)
// ==========================================
void audioCoreTask(void *param) {
  int32_t micRawBuf[I2S_DMA_BUF_LEN];
  int16_t pcmOutBuf[I2S_DMA_BUF_LEN];
  size_t bytesRead = 0, bytesWritten = 0;

  for (;;) {
    if (sysState.isRecording) {
      // Stream 24-bit samples from INMP441, downscale to 16-bit PCM
      i2s_read(I2S_NUM_0, micRawBuf, sizeof(micRawBuf), &bytesRead, portMAX_DELAY);
      size_t samples = bytesRead / 4;
      for (size_t i = 0; i < samples; i++) {
        pcmOutBuf[i] = (int16_t)(micRawBuf[i] >> 8);
      }
      if (activeAudioFile) {
        activeAudioFile.write((uint8_t*)pcmOutBuf, samples * sizeof(int16_t));
      }
    } else if (sysState.isPlaying && !sysState.isTouchPaused) {
      // Stream audio from active WAV file to MAX98357A DAC
      if (activeAudioFile && activeAudioFile.available() >= sizeof(pcmOutBuf)) {
        size_t n = activeAudioFile.read((uint8_t*)pcmOutBuf, sizeof(pcmOutBuf));
        i2s_write(I2S_NUM_1, pcmOutBuf, n, &bytesWritten, portMAX_DELAY);
        sysState.currentSamplePos += (n / sizeof(int16_t));
      } else {
        // End of file reached
        sysState.isPlaying = false;
      }
    } else {
      vTaskDelay(pdMS_TO_TICKS(5));
    }
  }
}

// ==========================================
// 5. CORE 0 MOTOR, ENCODER & UI LOOP (500 Hz)
// ==========================================
void uiMotorCoreTask(void *param) {
  TickType_t xLastWakeTime = xTaskGetTickCount();
  const TickType_t xFrequency = pdMS_TO_TICKS(2); // 500 Hz Loop

  for (;;) {
    // 1. Read 12-Bit AS5600 Reel Angle
    uint16_t angle = readAS5600Angle();
    int16_t delta = (int16_t)angle - (int16_t)sysState.lastAngle;
    if (delta > 2048) delta -= 4096;
    if (delta < -2048) delta += 4096;
    sysState.angularVelocity = delta;
    sysState.lastAngle = angle;

    // 2. TE TP-7 Touch-to-Pause & Motor Stall Detection
    // If motor is driven forward (+80 PWM) but reel velocity drops to ~0,
    // user has placed their finger on the reel to pause playback!
    if (sysState.isPlaying) {
      if (abs(delta) < 1 && !sysState.isTouchPaused) {
        sysState.isTouchPaused = true;
        setMotorDrive(0);
      } else if (abs(delta) >= 2) {
        // User turned or released reel
        sysState.isTouchPaused = false;
        setMotorDrive(80); // Resume tape reel drive
        
        // Scrub audio position relative to finger spin
        if (activeAudioFile && abs(delta) > 5) {
          int32_t sampleOffset = (int32_t)(delta * (SAMPLE_RATE * 0.05f));
          int32_t newPos = sysState.currentSamplePos + sampleOffset;
          if (newPos >= 0 && newPos < sysState.totalSamples) {
            sysState.currentSamplePos = newPos;
            activeAudioFile.seek(44 + newPos * sizeof(int16_t));
          }
        }
      }
    } else {
      setMotorDrive(0);
    }

    // 3. Check 2-Stage Rocker Switch for High-Speed Shuttle
    bool fwdPressed = (digitalRead(PIN_ROCKER_FWD) == LOW);
    bool rewPressed = (digitalRead(PIN_ROCKER_REW) == LOW);

    if (fwdPressed && activeAudioFile) {
      sysState.currentSamplePos += (SAMPLE_RATE * 2); // Jump forward 2s
      if (sysState.currentSamplePos > sysState.totalSamples) sysState.currentSamplePos = sysState.totalSamples;
      activeAudioFile.seek(44 + sysState.currentSamplePos * sizeof(int16_t));
      setMotorDrive(200); // High speed motor spin
    } else if (rewPressed && activeAudioFile) {
      sysState.currentSamplePos -= (SAMPLE_RATE * 2); // Jump backward 2s
      if (sysState.currentSamplePos < 0) sysState.currentSamplePos = 0;
      activeAudioFile.seek(44 + sysState.currentSamplePos * sizeof(int16_t));
      setMotorDrive(-200);
    }

    // 4. Memo Button (Hold-to-Record)
    bool memoPressed = (digitalRead(PIN_BTN_MEMO) == LOW);
    if (memoPressed && !sysState.isRecording) {
      sysState.isRecording = true;
      sysState.isMemoActive = true;
      digitalWrite(PIN_LED_REC, HIGH);
    } else if (!memoPressed && sysState.isMemoActive) {
      sysState.isRecording = false;
      sysState.isMemoActive = false;
      digitalWrite(PIN_LED_REC, LOW);
    }

    vTaskDelayUntil(&xLastWakeTime, xFrequency);
  }
}

// ==========================================
// 6. MAIN SYSTEM SETUP & TASK SPAWN
// ==========================================
void setup() {
  Serial.begin(115200);
  Wire.begin(PIN_I2C_SDA, PIN_I2C_SCL, 400000); // 400kHz Fast I2C

  pinMode(PIN_BTN_REC, INPUT_PULLUP);
  pinMode(PIN_BTN_MEMO, INPUT_PULLUP);
  pinMode(PIN_BTN_PLAY, INPUT_PULLUP);
  pinMode(PIN_BTN_MODE, INPUT_PULLUP);
  pinMode(PIN_ROCKER_FWD, INPUT_PULLUP);
  pinMode(PIN_ROCKER_REW, INPUT_PULLUP);
  pinMode(PIN_LED_REC, OUTPUT);
  digitalWrite(PIN_LED_REC, LOW);

  initMicrophone();
  initSpeaker();
  initMotor();

  SPI.begin(PIN_SD_SCK, PIN_SD_MISO, PIN_SD_MOSI, PIN_SD_CS);
  SD.begin(PIN_SD_CS);

  // Pin High-Priority Audio Task to Core 1
  xTaskCreatePinnedToCore(audioCoreTask, "AudioCore1", 4096, NULL, 3, NULL, 1);

  // Pin 500Hz UI & Motor Control Loop to Core 0
  xTaskCreatePinnedToCore(uiMotorCoreTask, "UIMotorCore0", 4096, NULL, 2, NULL, 0);

  Serial.println("DIY TP-7 Field Recorder v2.0 Online");
}

void loop() {
  // Main background loop handles BLE sync and battery telemetry
  vTaskDelay(pdMS_TO_TICKS(100));
}

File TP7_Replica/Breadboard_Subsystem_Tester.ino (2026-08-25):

/*
  DIY TP-7 Field Recorder - Breadboard Subsystem Tester & Diagnostic Tool
  
  Use this sketch to verify every jumper wire and breakout module on your breadboard
  one by one using interactive Serial Monitor commands at 115200 baud!

  Interactive Menu:
  [1] Scan I2C Bus (Finds AS5600 0x36 & OLED 0x3C)
  [2] Live Track AS5600 12-Bit Angle & Magnet Strength
  [3] Test N20 Motor Forward / Reverse / Brake PWM
  [4] Test INMP441 Microphone (Real-time I2S Audio Level Meter)
  [5] Test MAX98357A Speaker (Play 440Hz A4 Sine Tone)
  [6] Test MicroSD Card Read / Write Speed
  [7] Test Pushbuttons & Rocker Switch GPIOs
  [8] Run Full Audio Record & Playback Loopback Test
*/

#include <Arduino.h>
#include <Wire.h>
#include <driver/i2s.h>
#include <SD.h>
#include <SPI.h>

// Pin Definitions
#define PIN_I2S_MIC_WS      25
#define PIN_I2S_MIC_SCK     26
#define PIN_I2S_MIC_SD      33

#define PIN_I2S_SPK_DIN     22
#define PIN_I2S_SPK_BCLK    27
#define PIN_I2S_SPK_LRC     14

#define PIN_I2C_SDA         21
#define PIN_I2C_SCL         15
#define AS5600_ADDR         0x36

#define PIN_MOTOR_IN1       18
#define PIN_MOTOR_IN2       19

#define PIN_SD_CS           5
#define PIN_SD_MOSI         23
#define PIN_SD_MISO         12
#define PIN_SD_SCK          13

#define PIN_BTN_REC         32
#define PIN_BTN_MEMO        34
#define PIN_BTN_PLAY        35
#define PIN_BTN_MODE        36
#define PIN_ROCKER_FWD      39
#define PIN_ROCKER_REW      4
#define PIN_LED_REC         2

void printMenu() {
  Serial.println("\n========================================================");
  Serial.println("     DIY TP-7 BREADBOARD SUBSYSTEM DIAGNOSTIC TOOL      ");
  Serial.println("========================================================");
  Serial.println(" [1] Scan I2C Bus (AS5600 & OLED)");
  Serial.println(" [2] Monitor AS5600 Magnetic Angle & Touch Sensor");
  Serial.println(" [3] Test N20 Motor Drive (CW / CCW / Stall)");
  Serial.println(" [4] Monitor INMP441 I2S Microphone Volume Level");
  Serial.println(" [5] Play 440Hz Test Tone on MAX98357A Speaker");
  Serial.println(" [6] Benchmark MicroSD Card Read/Write Speed");
  Serial.println(" [7] Test All Hardware Buttons & Rocker Switch");
  Serial.println(" [8] 3-Second Audio Record & Playback Loopback Test");
  Serial.println("========================================================");
  Serial.print("Enter option (1-8): ");
}

void scanI2C() {
  Serial.println("\nScanning I2C Bus (SDA:21, SCL:15)...");
  byte count = 0;
  for (byte i = 1; i < 127; i++) {
    Wire.beginTransmission(i);
    if (Wire.endTransmission() == 0) {
      Serial.printf(" [FOUND] Device at I2C address 0x%02X", i);
      if (i == 0x36) Serial.print(" -> AS5600 12-Bit Magnetic Angle Sensor!");
      else if (i == 0x3C || i == 0x3D) Serial.print(" -> SSD1306 OLED Display!");
      Serial.println();
      count++;
    }
  }
  if (count == 0) Serial.println(" [WARNING] No I2C devices found. Check 3.3V power and SDA/SCL pull-ups.");
}

void testAS5600() {
  Serial.println("\nTracking AS5600 Angle. Spin the tape reel! (Send any key to stop)");
  while (!Serial.available()) {
    Wire.beginTransmission(AS5600_ADDR);
    Wire.write(0x0C); // Angle register
    if (Wire.endTransmission(false) == 0 && Wire.requestFrom(AS5600_ADDR, (uint8_t)2) == 2) {
      uint16_t rawAngle = (Wire.read() << 8) | Wire.read();
      rawAngle &= 0x0FFF;
      float deg = (rawAngle * 360.0f) / 4096.0f;
      Serial.printf("Reel Angle: %6.1f° | Raw: %4d | [", deg, rawAngle);
      int bars = (int)(deg / 10.0f);
      for (int b = 0; b < 36; b++) Serial.print(b < bars ? "=" : " ");
      Serial.println("]");
    } else {
      Serial.println(" [ERROR] Failed to read AS5600 sensor.");
      break;
    }
    delay(100);
  }
  while (Serial.available()) Serial.read();
}

void testMotor() {
  Serial.println("\nTesting N20 Gearmotor Drive...");
  ledcSetup(0, 20000, 8);
  ledcSetup(1, 20000, 8);
  ledcAttachPin(PIN_MOTOR_IN1, 0);
  ledcAttachPin(PIN_MOTOR_IN2, 1);

  Serial.println(" -> Spinning Forward (80/255 duty cycle for 2 seconds)...");
  ledcWrite(0, 80); ledcWrite(1, 0);
  delay(2000);

  Serial.println(" -> Braking...");
  ledcWrite(0, 0); ledcWrite(1, 0);
  delay(500);

  Serial.println(" -> Spinning Reverse (80/255 duty cycle for 2 seconds)...");
  ledcWrite(0, 0); ledcWrite(1, 80);
  delay(2000);

  Serial.println(" -> Motor Stopped.");
  ledcWrite(0, 0); ledcWrite(1, 0);
}

void playTestTone() {
  Serial.println("\nPlaying 440Hz Sine Wave on MAX98357A Speaker for 2 seconds...");
  i2s_config_t cfg = {
    .mode = (i2s_mode_t)(I2S_MODE_MASTER | I2S_MODE_TX),
    .sample_rate = 44100,
    .bits_per_sample = I2S_BITS_PER_SAMPLE_16BIT,
    .channel_format = I2S_CHANNEL_FMT_ONLY_LEFT,
    .communication_format = I2S_COMM_FORMAT_STAND_I2S,
    .intr_alloc_flags = ESP_INTR_FLAG_LEVEL1,
    .dma_buf_count = 8,
    .dma_buf_len = 128
  };
  i2s_pin_config_t pins = {
    .bck_io_num = PIN_I2S_SPK_BCLK,
    .ws_io_num = PIN_I2S_SPK_LRC,
    .data_out_num = PIN_I2S_SPK_DIN,
    .data_in_num = I2S_PIN_NO_CHANGE
  };
  i2s_driver_install(I2S_NUM_1, &cfg, 0, NULL);
  i2s_set_pin(I2S_NUM_1, &pins);

  int16_t toneBuf[128];
  for (int i = 0; i < 128; i++) {
    toneBuf[i] = (int16_t)(sin((2.0 * PI * 440.0 * i) / 44100.0) * 8000.0);
  }

  size_t bytesWritten;
  uint32_t start = millis();
  while (millis() - start < 2000) {
    i2s_write(I2S_NUM_1, toneBuf, sizeof(toneBuf), &bytesWritten, portMAX_DELAY);
  }
  i2s_driver_uninstall(I2S_NUM_1);
  Serial.println(" [OK] Test Tone Complete.");
}

void testSDCard() {
  Serial.println("\nTesting MicroSD SPI Communication...");
  SPI.begin(PIN_SD_SCK, PIN_SD_MISO, PIN_SD_MOSI, PIN_SD_CS);
  if (!SD.begin(PIN_SD_CS)) {
    Serial.println(" [FAIL] MicroSD Card failed to mount. Check CS:5, MOSI:23, MISO:12, SCK:13.");
    return;
  }
  uint64_t totalMB = SD.totalBytes() / (1024 * 1024);
  uint64_t usedMB = SD.usedBytes() / (1024 * 1024);
  Serial.printf(" [OK] MicroSD Card Mounted! Total: %llu MB | Used: %llu MB\n", totalMB, usedMB);

  Serial.println(" -> Benchmarking WAV write speed...");
  File f = SD.open("/test_bench.raw", FILE_WRITE);
  if (f) {
    uint8_t dummyBuf[512];
    memset(dummyBuf, 0x55, sizeof(dummyBuf));
    uint32_t t0 = millis();
    for (int i = 0; i < 200; i++) { // Write 100 KB
      f.write(dummyBuf, sizeof(dummyBuf));
    }
    f.close();
    uint32_t elapsed = millis() - t0;
    float kbps = (100.0f / (elapsed / 1000.0f));
    Serial.printf(" [OK] Write Speed: %.2f KB/s (Requires >88.2 KB/s for 44.1kHz 16-bit WAV)\n", kbps);
    SD.remove("/test_bench.raw");
  }
}
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

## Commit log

2026-08-24 Add 3D STL enclosure models, PCB manufacturing guide, KiCad netlist, BOM, and upgraded firmware v2.0 with authentic TP-7 touch-to-pause
    [TP7_Chassis_Bottom_Lid.stl, TP7_Main_Chassis_Top.stl, TP7_Motorized_Tape_Reel.stl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]
2026-08-25 Add Arduino IDE & ESP32 prototyping setup guide
2026-08-25 Add commercialization, legal compliance, and regulatory guide PDF
